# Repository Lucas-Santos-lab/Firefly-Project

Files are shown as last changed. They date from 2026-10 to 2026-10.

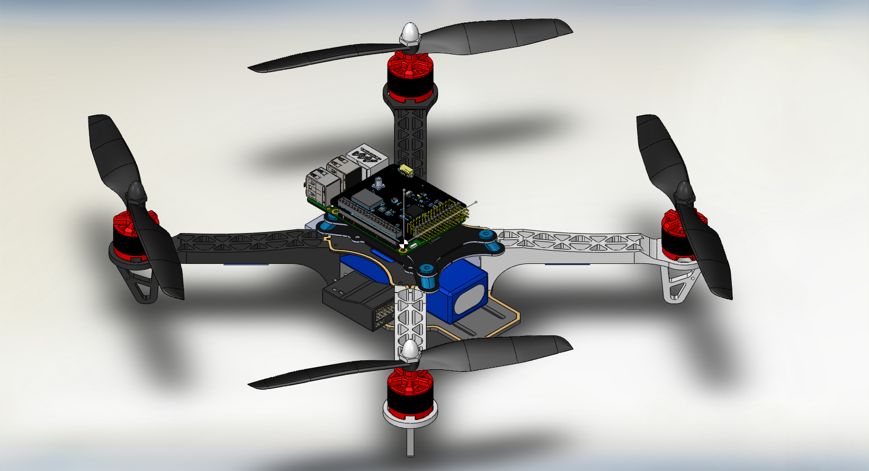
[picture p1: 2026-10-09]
Hardware/CAD/dji_f330/frame_assembly.PNG

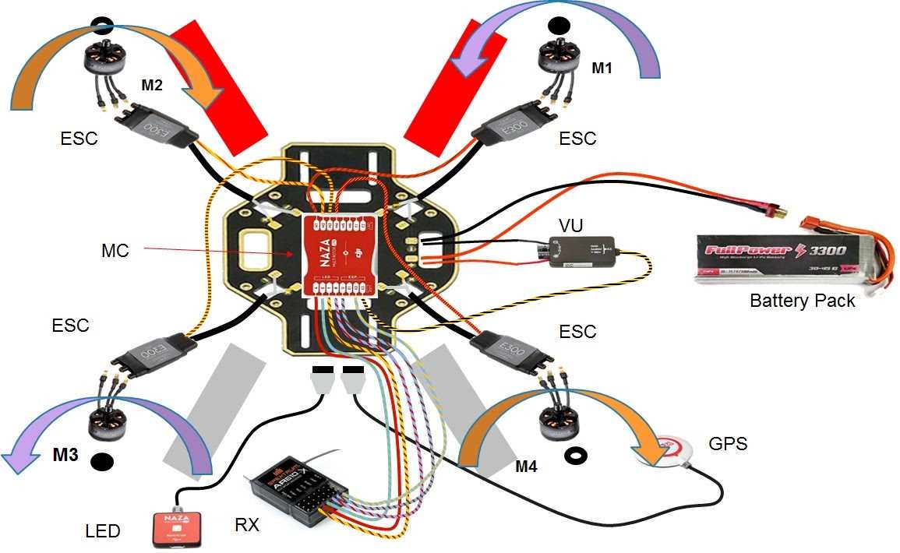
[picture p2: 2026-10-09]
Hardware/Diagrams/naza-m_lite_wiring_diagram.jpg

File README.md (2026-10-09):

# Firefly Project

Recovery, configuration and calibration of a quadcopter for controlled flight, developed over three academic semesters. This document covers **Semester 1**.

> **Status:** Semester 1 objective achieved 07/10/2026 · **Deadline:** 01/12/2026

---

## Introduction

The project started with a pre-existing **F450 frame running ArduCopter**. It was discarded in the first weeks: the flight controller was damaged and oxidized. Serial monitor tests returned the following error, which prevented the controller from booting:

```
PANIC! Baro: internal sensor failed to respond
```

Development continued on a second airframe: a **DJI F330 frame with a DJI Naza-M Lite** flight controller. This is the platform documented in this repository.

---

## Semester 1 — Scope

| # | Task | Status |
|---|---|---|
| 1 | Component verification (motors, ESCs, battery, receiver) and replacement of faulty parts | Completed |
| 2 | Download and update of the Naza-M Lite driver and firmware | Completed |
| 3 | Configuration and calibration (receiver binding, ESC throttle range, Naza-M Lite Assistant setup) | Completed |

**Objective:** perform short, controlled flights.

**Result:** short, controlled untethered flights were performed successfully.

---

## Hardware

| Component | Specification | Qty. |
|---|---|---|
| Frame | DJI F330 (Quad X) | 1 |
| Flight controller | DJI Naza-M Lite | 1 |
| Motors | Brushless 2212 920KV | 4 |
| ESCs | EMAX SimonK 30A | 4 |
| Radio | HT-10A 2.4 GHz transmitter + receiver | 1 |
| Battery | LiPo | 1 |

---

## Software environment

| Item | Configuration |
|---|---|
| OS | Windows (required by DJI tools) |
| Configuration software | DJI Naza-M Lite Assistant |
| Driver | DJI WIN Driver (unsigned; requires driver signature enforcement to be disabled during installation) |

Download links: [`Firmware/readme.md`](Firmware/readme.md)

---

## Repository structure

| Path | Contents |
|---|---|
| [`Docs/Repair instructions.docx`](Docs/Repair%20instructions.docx) | Step-by-step repair, configuration and calibration procedure |
| [`Docs/Pictures/`](Docs/Pictures/) | Photos and videos of the process |
| [`Docs/DIP/`](Docs/DIP/) | Course (DIP) deliverable documents |
| [`Hardware/CAD/dji_f330/`](Hardware/CAD/dji_f330/) | F330 frame CAD model (SolidWorks), sourced from GrabCAD |
| [`Hardware/Datasheets/`](Hardware/Datasheets/) | Naza-M Lite manual, ESC manual and reference links |
| [`Hardware/Diagrams/`](Hardware/Diagrams/) | Naza-M Lite wiring diagram |
| [`Firmware/`](Firmware/) | Firmware and software download links |

---

## Future work

The Semester 1 platform is a working baseline. Upgrades and further additions will be defined in the following semesters.

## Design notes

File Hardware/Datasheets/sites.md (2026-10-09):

HT10A 2.4G radio remote control User Manual
https://fccid.io/2BDLE-HT-10A/User-Manual/User-Manual-8720161

2212 Brushless Motor
https://components101.com/motors/2212-brushless-motor

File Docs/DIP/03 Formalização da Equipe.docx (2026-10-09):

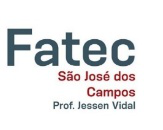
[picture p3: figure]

| | Curso Superior de Tecnologia em Manufatura Avançada
Formalização da equipe | | DIP XXXXXX
Professor de dip
Professores envolvidos no projeto

Nome da Equipe | | XXXXXXXXXX

Integrantes
| Nome Completo | | Foto
1
2
3
4
5

tema do projeto

XXXXXXXX

repositório de documentos, gerenciamento de atividades e portifólio

XXXXXXXX

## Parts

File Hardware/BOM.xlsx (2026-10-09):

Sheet: BOM
Firefly Project — Bill of Materials (DJI F330 + Naza-M Lite)
Estimated prices. BRL = USD × exchange rate × Brazil market factor (see Assumptions sheet).
# | Group | Component | Specification | Qty | Unit price (USD) | Subtotal (USD) | Unit price (BRL) | Subtotal (BRL) | Source / notes
Aircraft
1 | Frame | DJI F330 (Quad X), clone | 330 mm wheelbase, PDB integrated in bottom plate | 1 | US$15.00 | US$15.00 | R$135.08 | R$135.08 | Estimate. Original DJI F330 discontinued; clone kits typical.
2 | Flight controller | DJI Naza-M Lite | Main controller + PMU + LED module | 1 | US$38.99 | US$38.99 | R$351.11 | R$351.11 | GetFPV list price (out of stock on 2026-10-08). Discontinued; used market varies.
3 | Motors | Brushless 2212 920KV | CW/CCW, 3S | 4 | US$9.00 | US$36.00 | R$81.05 | R$324.18 | Estimate, generic A2212 920KV.
4 | ESCs | EMAX SimonK 30A | 2-4S, linear BEC 2A/5V | 4 | US$12.00 | US$48.00 | R$108.06 | R$432.24 | Estimate. Rating per EMAX SimonK datasheet in Hardware/datasheets.
5 | Radio | HotRC HT-10A 2.4 GHz | 10-channel transmitter + receiver | 1 | US$40.00 | US$40.00 | R$360.20 | R$360.20 | Estimate.
6 | Propellers | 8045 CW/CCW | Plastic, 8 in, sets of 1 CW + 1 CCW | 4 | US$2.00 | US$8.00 | R$18.01 | R$72.04 | Estimate. 2 pairs mounted + 2 spare pairs. Prop size not confirmed on the aircraft.
7 | Battery | LiPo 3S 2200 mAh 25C+ | XT60 or T-plug | 1 | US$22.00 | US$22.00 | R$198.11 | R$198.11 | Estimate. ASSUMPTION: battery spec not documented; update to actual cells/capacity.
 |  | Aircraft subtotal |  |  |  | US$207.99 |  | R$1872.96
Tools and support equipment
8 | Tools | LiPo balance charger | IMAX B6 class, 1-6S | 1 | US$25.00 | US$25.00 | R$225.13 | R$225.13 | Estimate.
9 | Tools | LiPo cell checker | 1-8S voltage display/alarm | 1 | US$5.00 | US$5.00 | R$45.03 | R$45.03 | Estimate. Used in component verification.
10 | Tools | Servo / ESC tester | PWM 1000-2000 µs | 1 | US$6.00 | US$6.00 | R$54.03 | R$54.03 | Estimate. Used in motor/ESC verification.
 |  | Tools subtotal |  |  |  | US$36.00 |  | R$324.18
 |  | TOTAL |  |  |  | US$243.99 |  | R$2197.14

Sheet: Assumptions
Firefly Project — BOM assumptions
Parameter | Value | Notes
USD/BRL exchange rate | 5.0028 | Commercial rate on 2026-10-07 15:45 (renovainvest.com.br/dolar-hoje). Update before use.
Brazil market factor | 1.80x | Multiplier over the converted USD price to approximate the Brazilian retail price (import tax, ICMS, shipping, reseller margin). Estimate; adjust to quotes from Mercado Livre or local stores.
Price reference date | 2026-10-08 | USD prices are typical US retail values for generic/clone parts unless the Source column says otherwise.
Legend
Blue text on yellow fill = editable input. Black = formula. Green = link to this sheet.

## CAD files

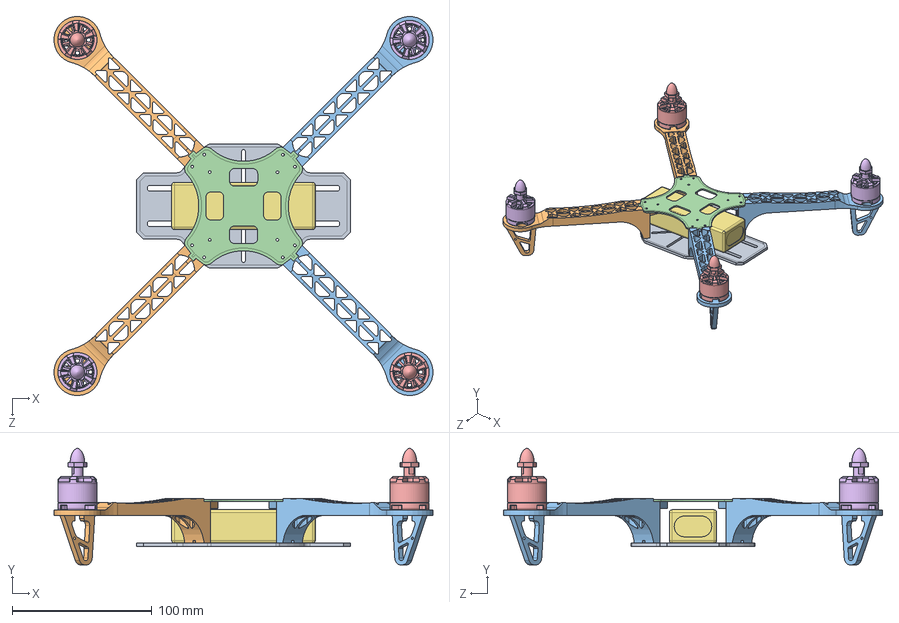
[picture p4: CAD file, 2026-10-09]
Hardware/CAD/dji_f330/frame_assembly.SLDASM
271.6 x 83.6 x 271.6 mm
DJI_F330_bottom_plate
DJI_F330_arm_black x 2
DJI_F330_arm_white x 2
DJI_F330_top_plate
Motor_CCW x 2
Motor_CW x 2
LiPo

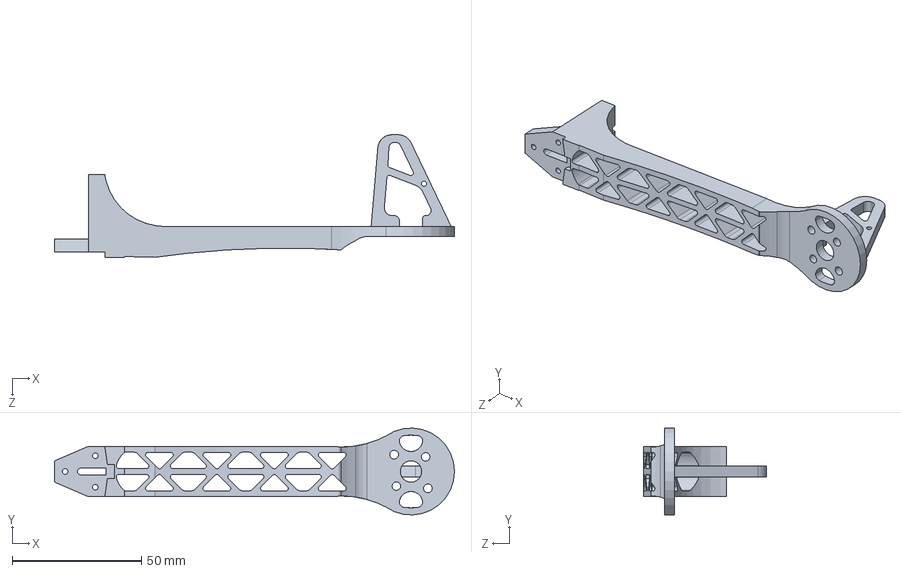
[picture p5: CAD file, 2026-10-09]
Hardware/CAD/dji_f330/DJI_F330_arm_black.SLDPRT
155.0 x 33.7 x 47.5 mm

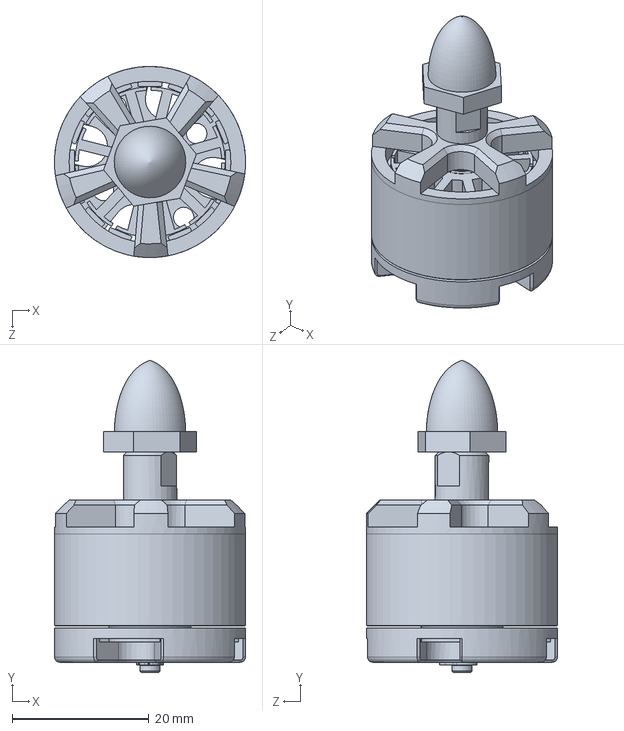
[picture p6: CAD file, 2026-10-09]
Hardware/CAD/dji_f330/Motor_CCW.SLDPRT
28.0 x 45.7 x 28.0 mm

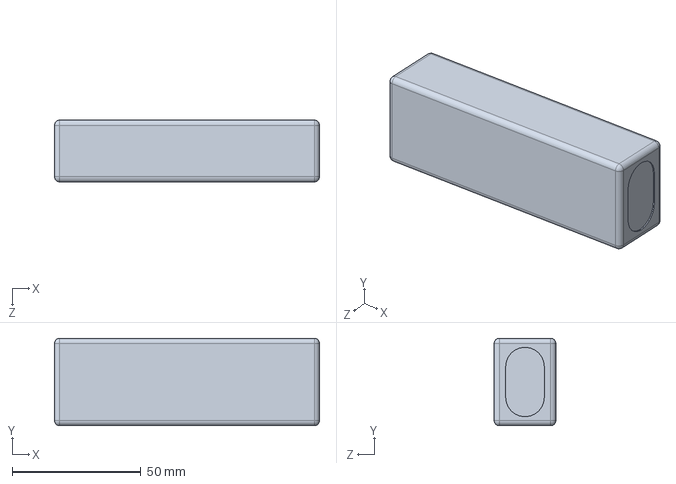
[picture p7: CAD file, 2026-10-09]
Hardware/CAD/dji_f330/LiPo.SLDPRT
103.0 x 34.0 x 24.0 mm

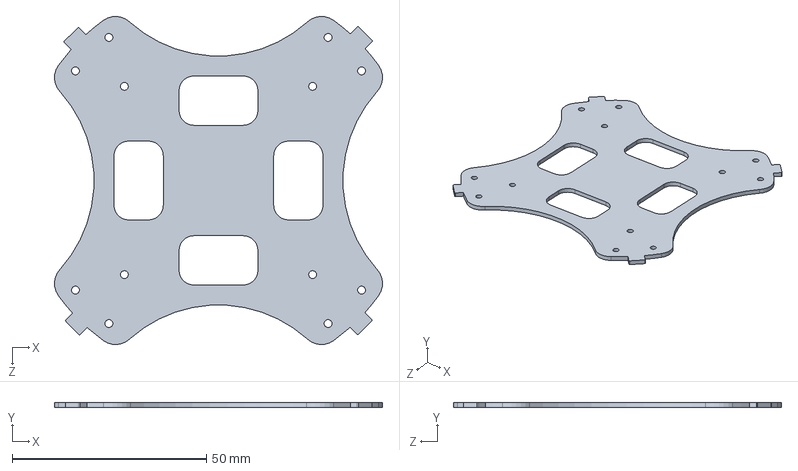
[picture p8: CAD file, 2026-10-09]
Hardware/CAD/dji_f330/DJI_F330_top_plate.SLDPRT
84.5 x 1.41 x 84.5 mm

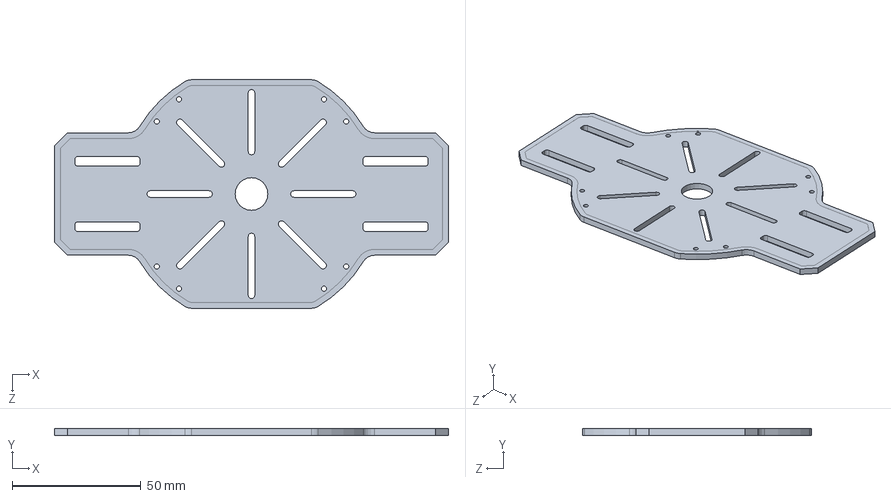
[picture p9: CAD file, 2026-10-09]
Hardware/CAD/dji_f330/DJI_F330_bottom_plate.SLDPRT
153.2 x 2.55 x 88.9 mm

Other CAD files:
Hardware/CAD/dji_f330/DJI_F330_arm_red.SLDPRT
Hardware/CAD/dji_f330/Motor_CW.SLDPRT
Hardware/CAD/dji_f330/DJI_F330_arm_white.SLDPRT

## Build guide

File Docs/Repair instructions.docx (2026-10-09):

DJI NAZA-M LITE REPAIR MANUAL

F330 FRAME

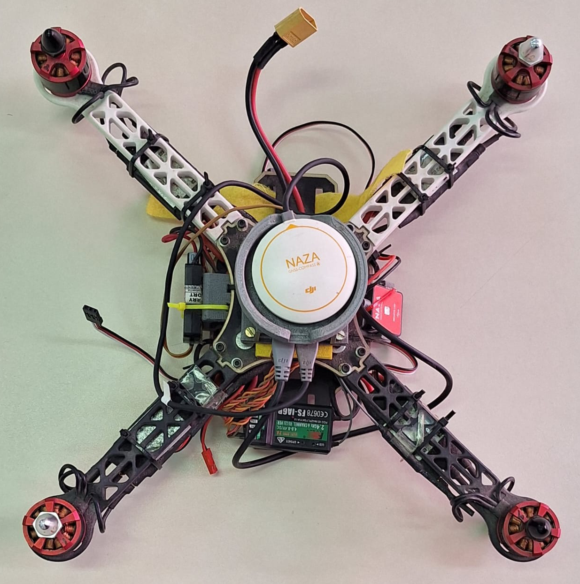
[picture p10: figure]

Repair Instructions

1. Check components & replace malfunctioning ones
2. Download drivers & update firmware
1. Ground control setup, Flight calibration & Tests
3. Final result

Check & replace components

Use a lipo bettery cell checker and servo tester to test the four brushless motors and the battery integrity, wich in this case was ok.

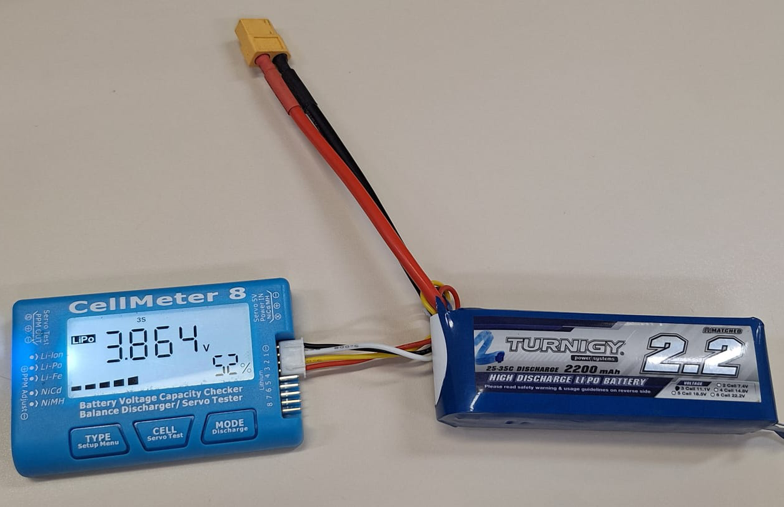
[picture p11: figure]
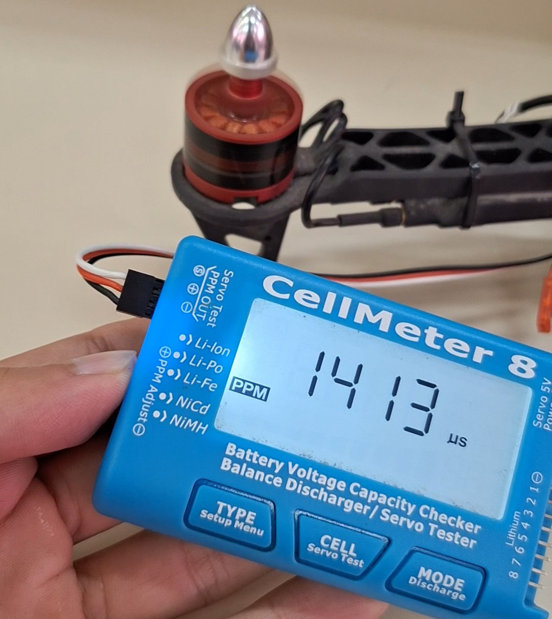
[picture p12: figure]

The previous remote controller was lost, so the receiver wil have to be replaced.

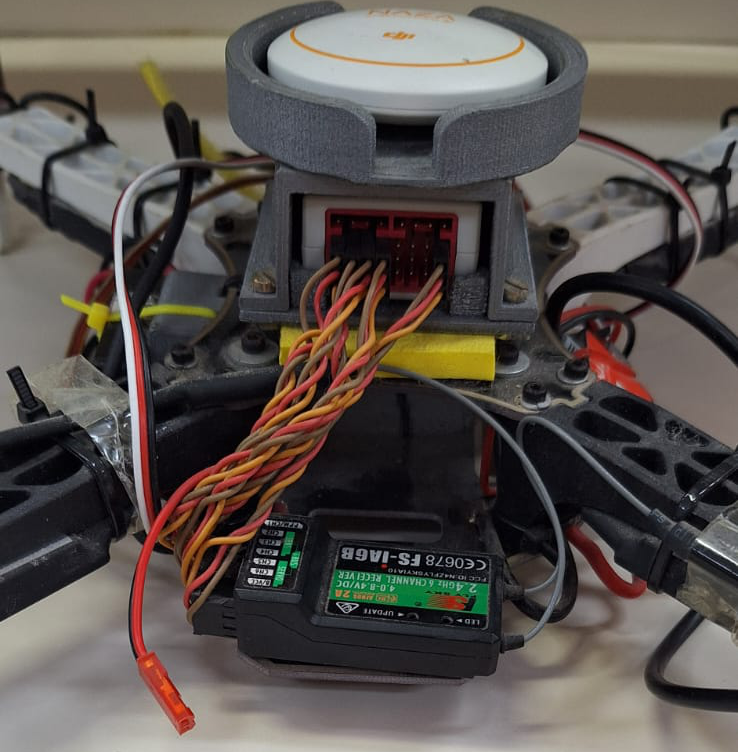
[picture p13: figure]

Disconnect the old receiver → plug the battery to the drone → connect one motor to the receiver to power it on → click the bind button on the receiver → in the RC select bind set > start. It should appear a “succesfull bind” message.

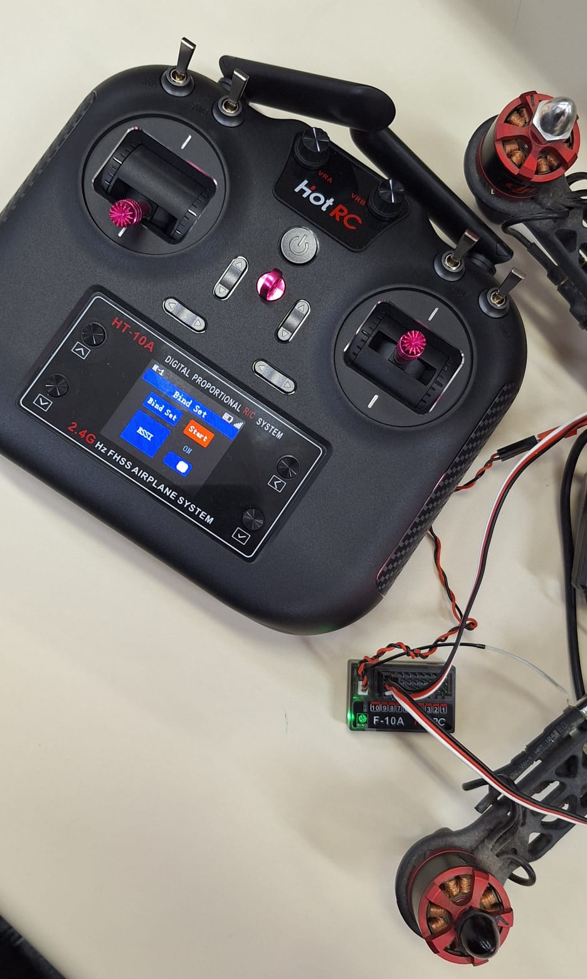
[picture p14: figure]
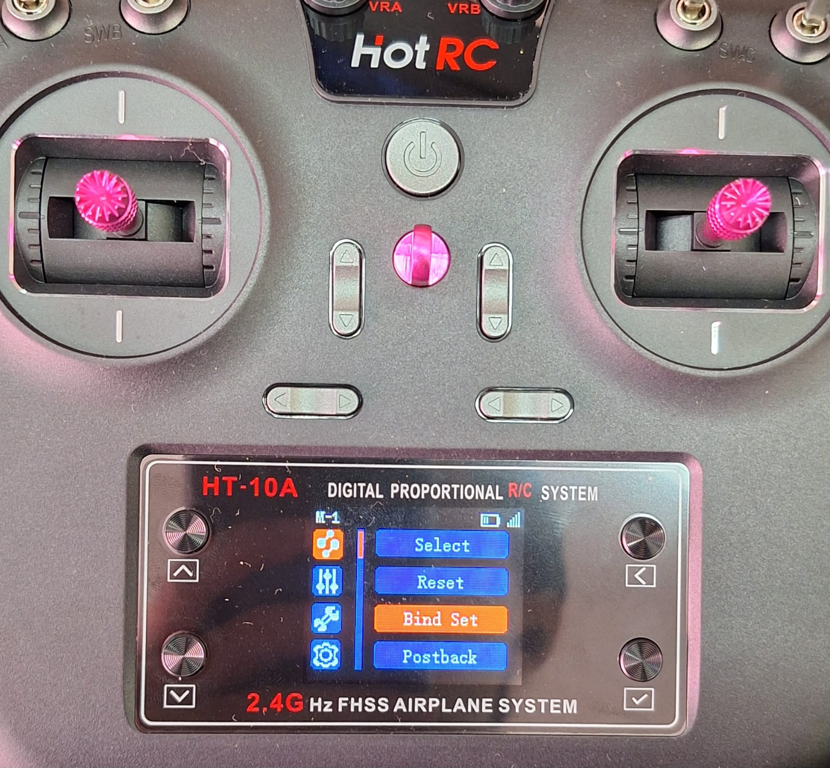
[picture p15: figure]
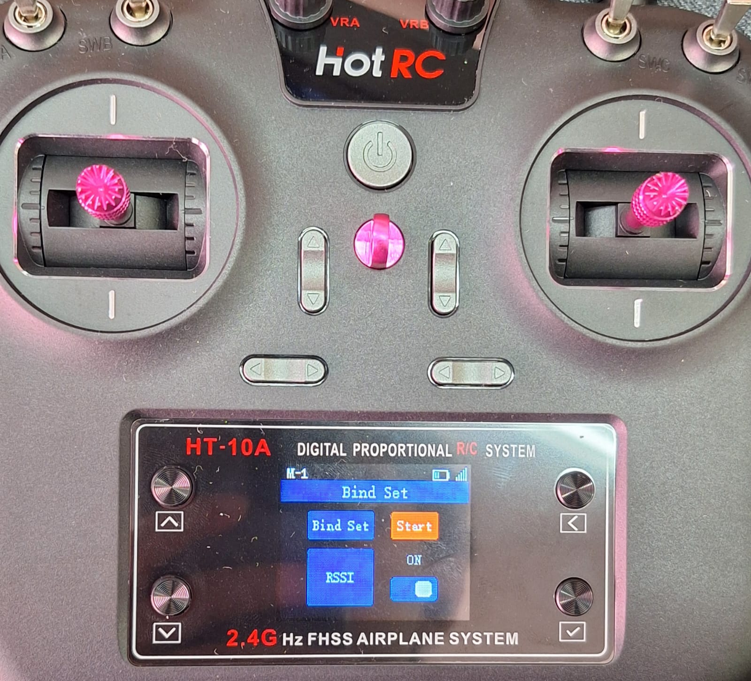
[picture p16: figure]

After binding, calibrate the four motors to the remote controller, for ach one follow these steps:

Unplug the baterry → connect one motor to CH3 (default calibration channel) → put the throttle stick in maximum up position →plug the battery, it should make a beep to signalize the calibration started → put the throttle stick in maximum down position, it should make a beep to signalize it is calibrated → Repeat the process for the remaining motors

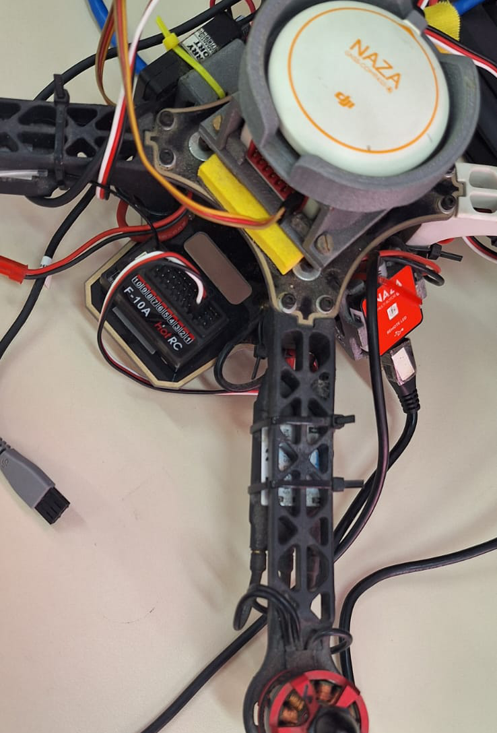
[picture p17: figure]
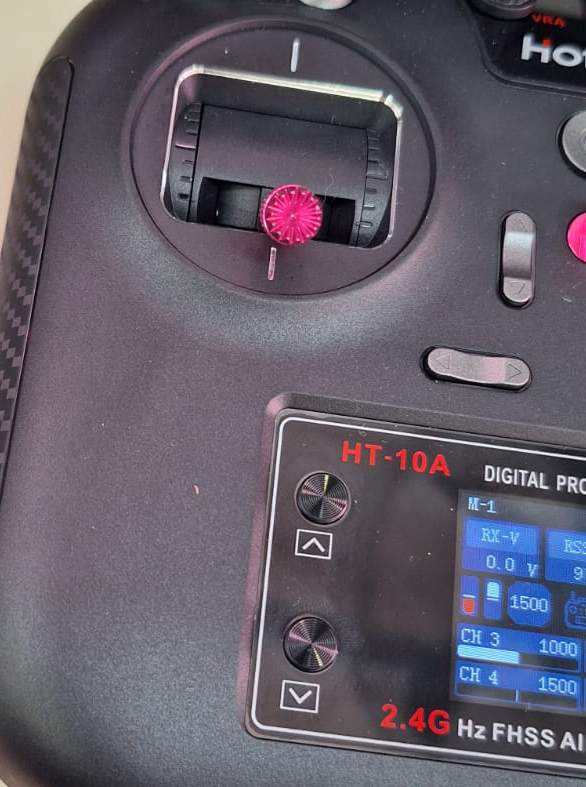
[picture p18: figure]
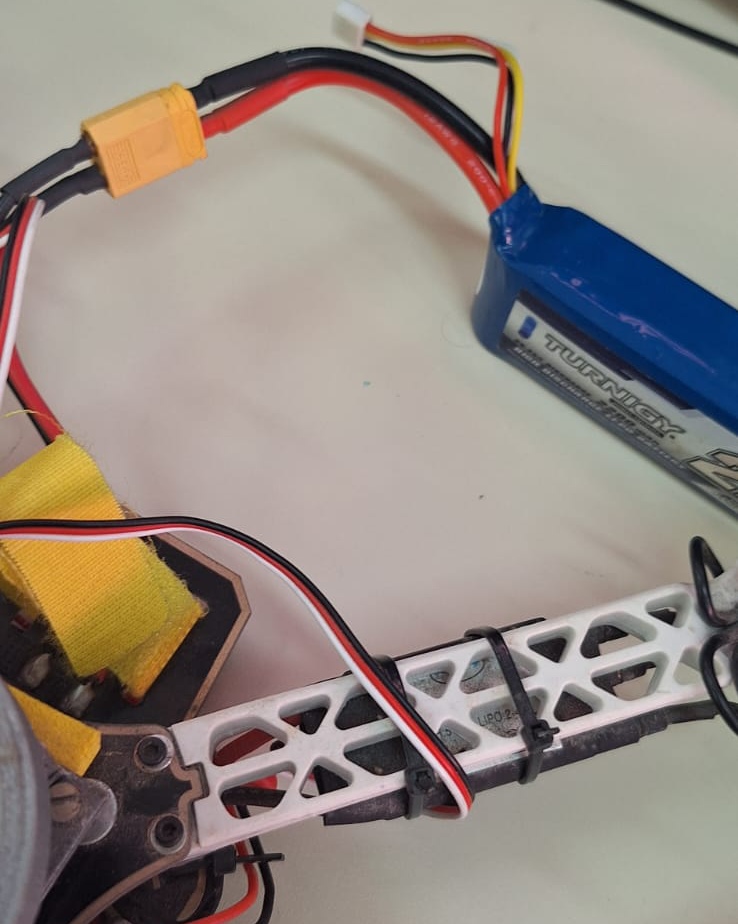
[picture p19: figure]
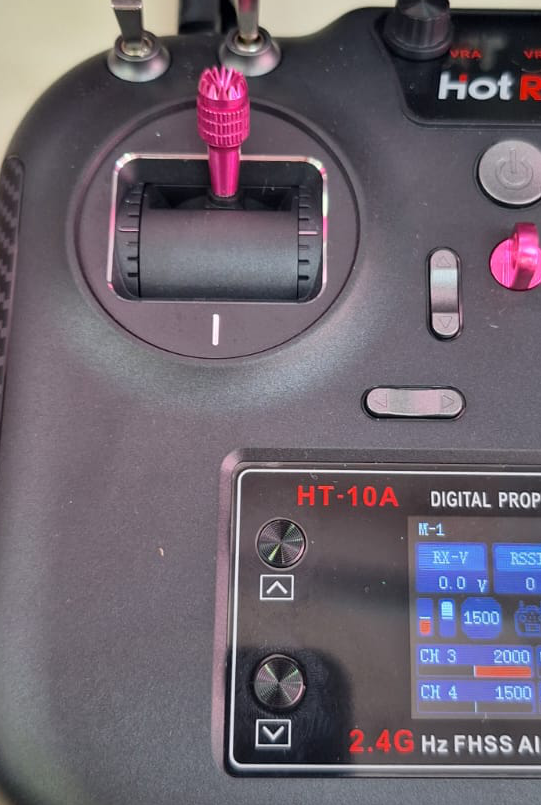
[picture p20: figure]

Connect the new receiver channels to the main controller according to the manual. In this case:

A – CH1 (Roll)
E – CH2 (Elevator)
T – CH3 (Throtle)
R – CH4 (Rudder)
U – CH5 (Flight modes)

If you want to add more functions to the RC, connect the X1, X2 and X3, then configure each function in naza assistant later.

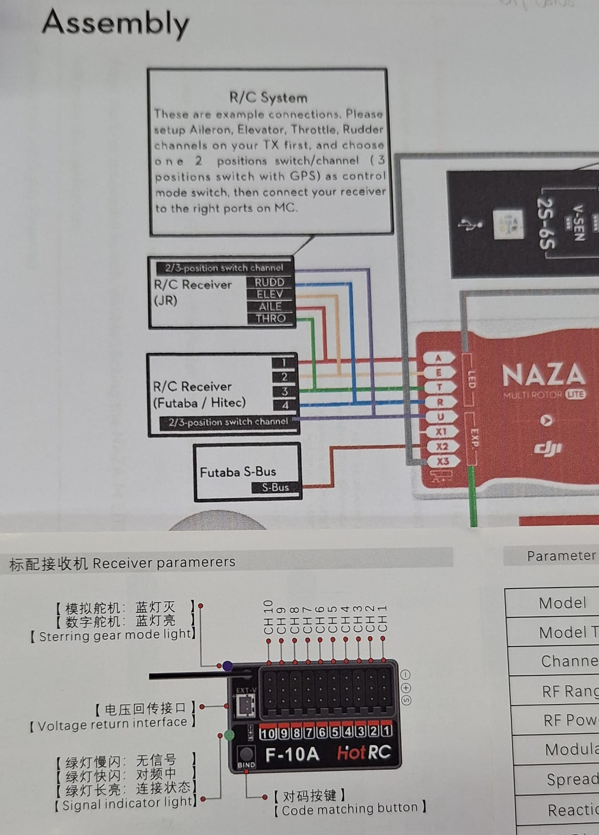
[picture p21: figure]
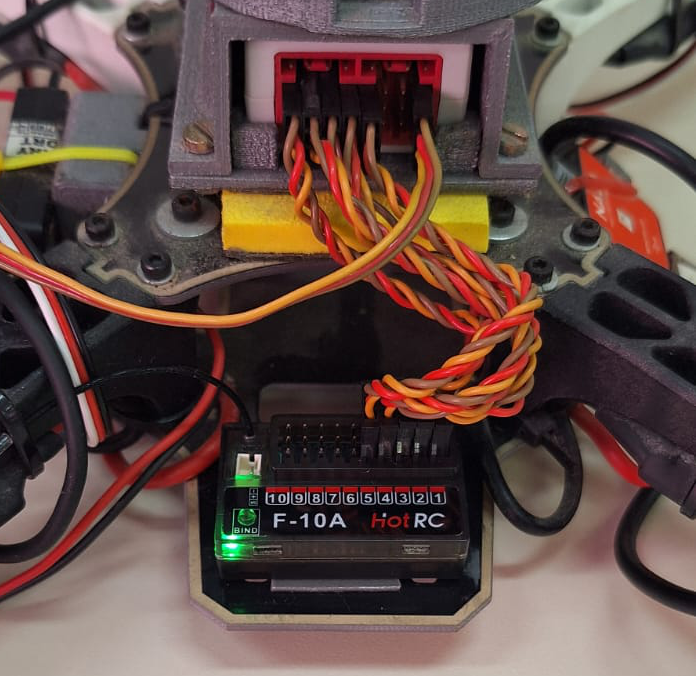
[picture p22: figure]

Download drivers & Update firmware

First, install naza m-lite assistant and WIN drivers in dji’s site.
https://www.dji.com/br/downloads/products/naza-m-lite#tuning_params
https://www.dji.com/br/downloads/softwares/other-dji-win

After installing follow these steps on windows:

1. Disable driver signature enforcement to install dji drivers (It think It’s a virus beacause it doesn’t have digital signature)
> Settings → System → Recovery → Advanced startup (click Restart now) → Troubleshoot → Advanced options → Startup Settings → Restart → Press F7

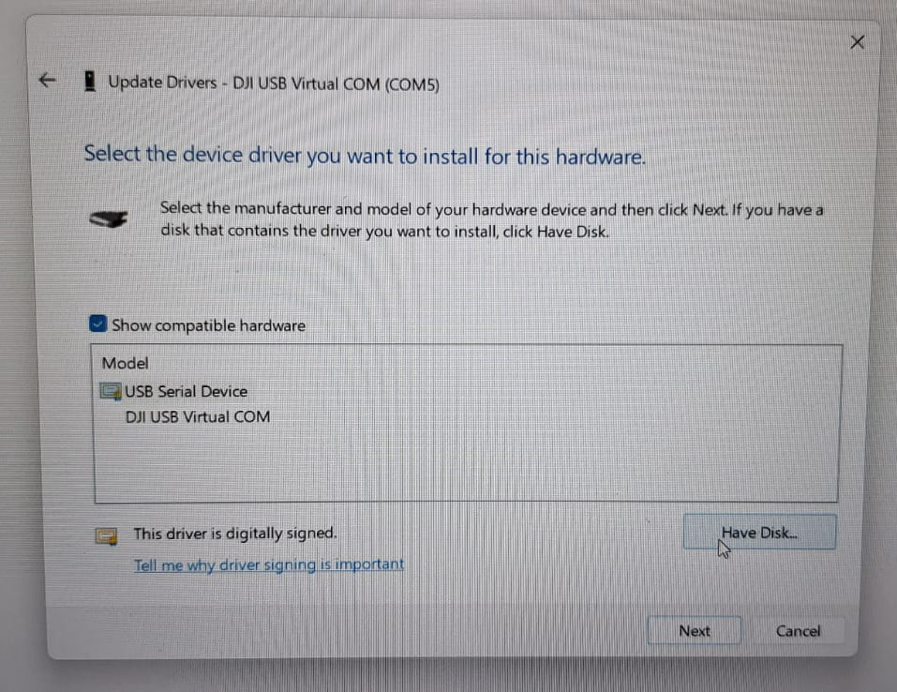
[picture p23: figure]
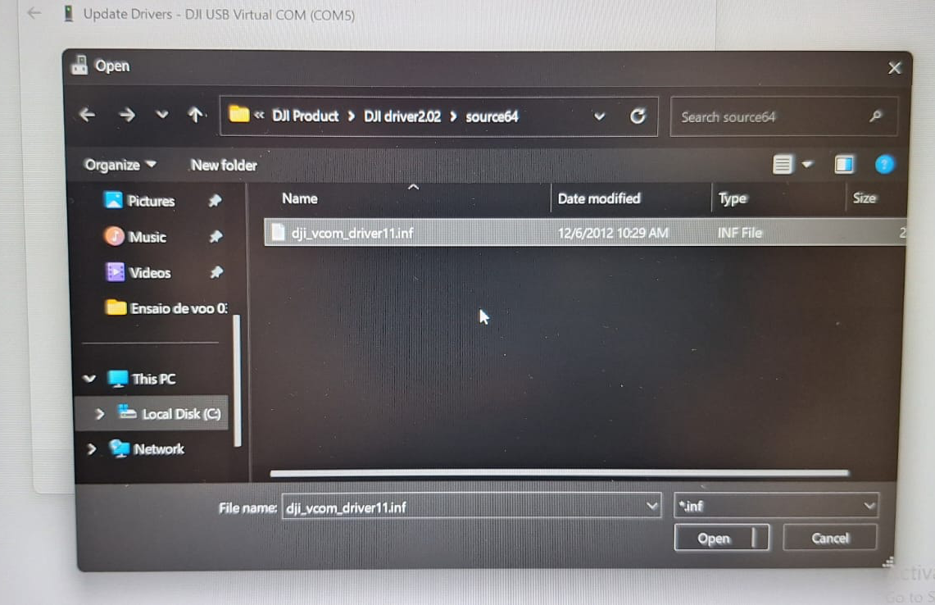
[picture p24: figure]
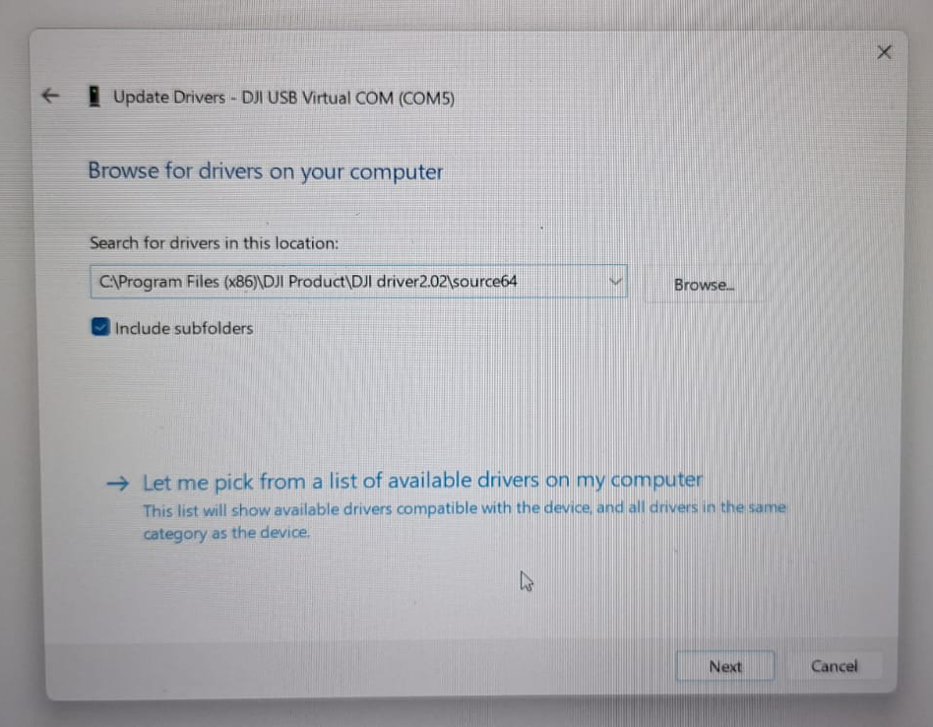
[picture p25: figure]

2. Execute the exe with privileges in windows power shell as admin
> Start-Process -FilePath "C:\Users\[user]\OneDrive\Desktop\DJI_WIN_Driver_Installer.exe" -Verb RunAs

Connect the main controller to your PC → Device manager → COM and LPT ports → serial USB device (COM5) → update driver → browse my computer for drivers → let me pick from a list of available drivers on my computer → have disk... → browse → select DJI driver in DJI product folder

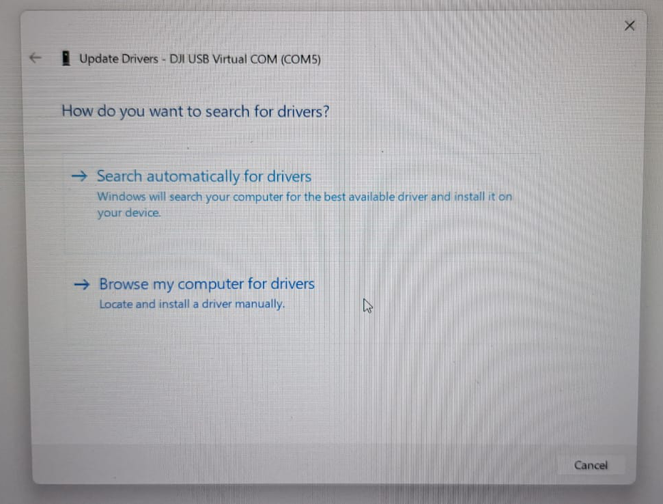
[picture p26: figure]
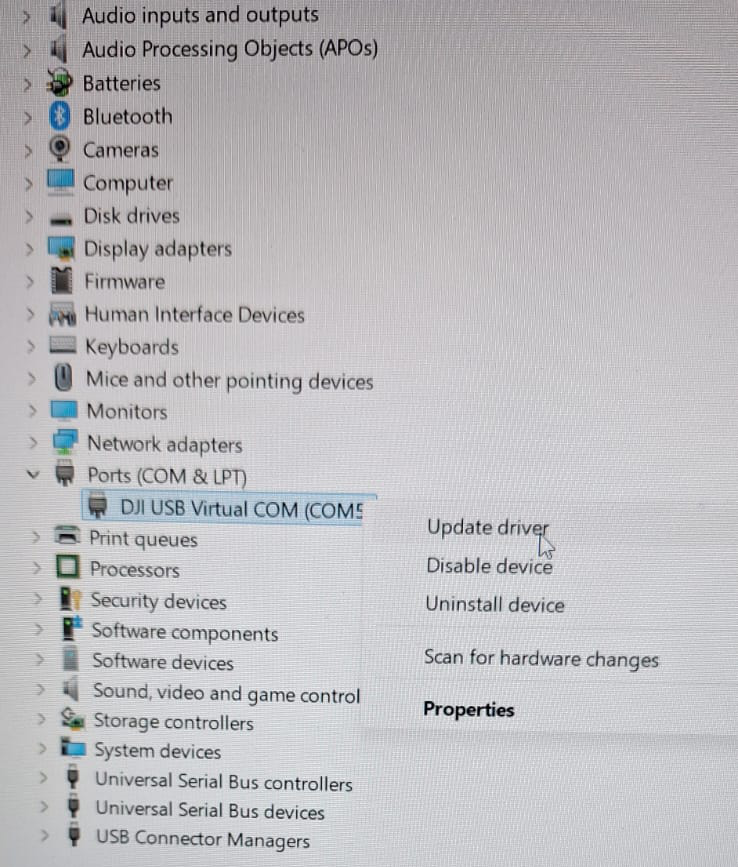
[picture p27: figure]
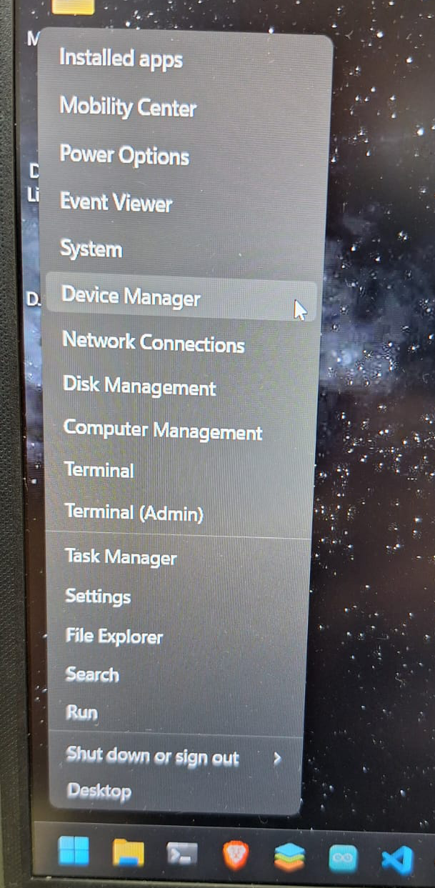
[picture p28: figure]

If you followed the steps correctly, your computer should recognize the main controller and you can now configure the drone in the flight assistant.

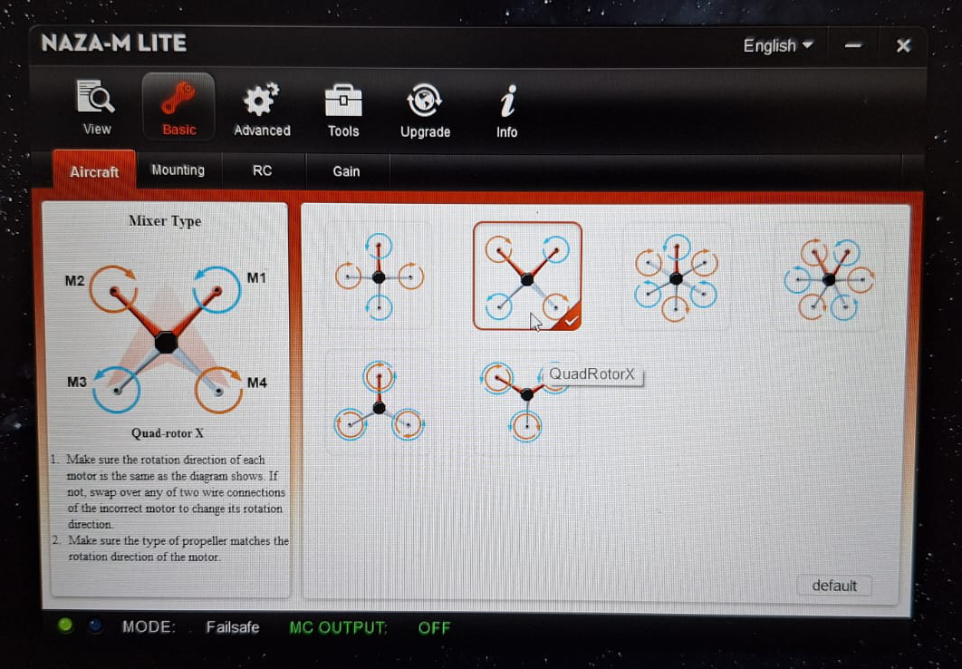
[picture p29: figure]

Ground control setup, calibration & tests

Execute naza assistant → configure as quad-rotorX or quad-rotor 1 according to the wiring of the motors
